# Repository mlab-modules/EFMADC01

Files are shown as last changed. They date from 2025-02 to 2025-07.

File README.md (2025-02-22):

# EFMADC01 - Electric Field Mill ADC Module

The **EFMADC01** module is designed to provide an **analog front-end** and **ADC conversion** for [Electric Field Mill sensor](https://github.com/UniversalScientificTechnologies/THUNDERMILL01) development and experiments. It processes analog signals from the field mill electrodes and converts them into digital data for further processing.

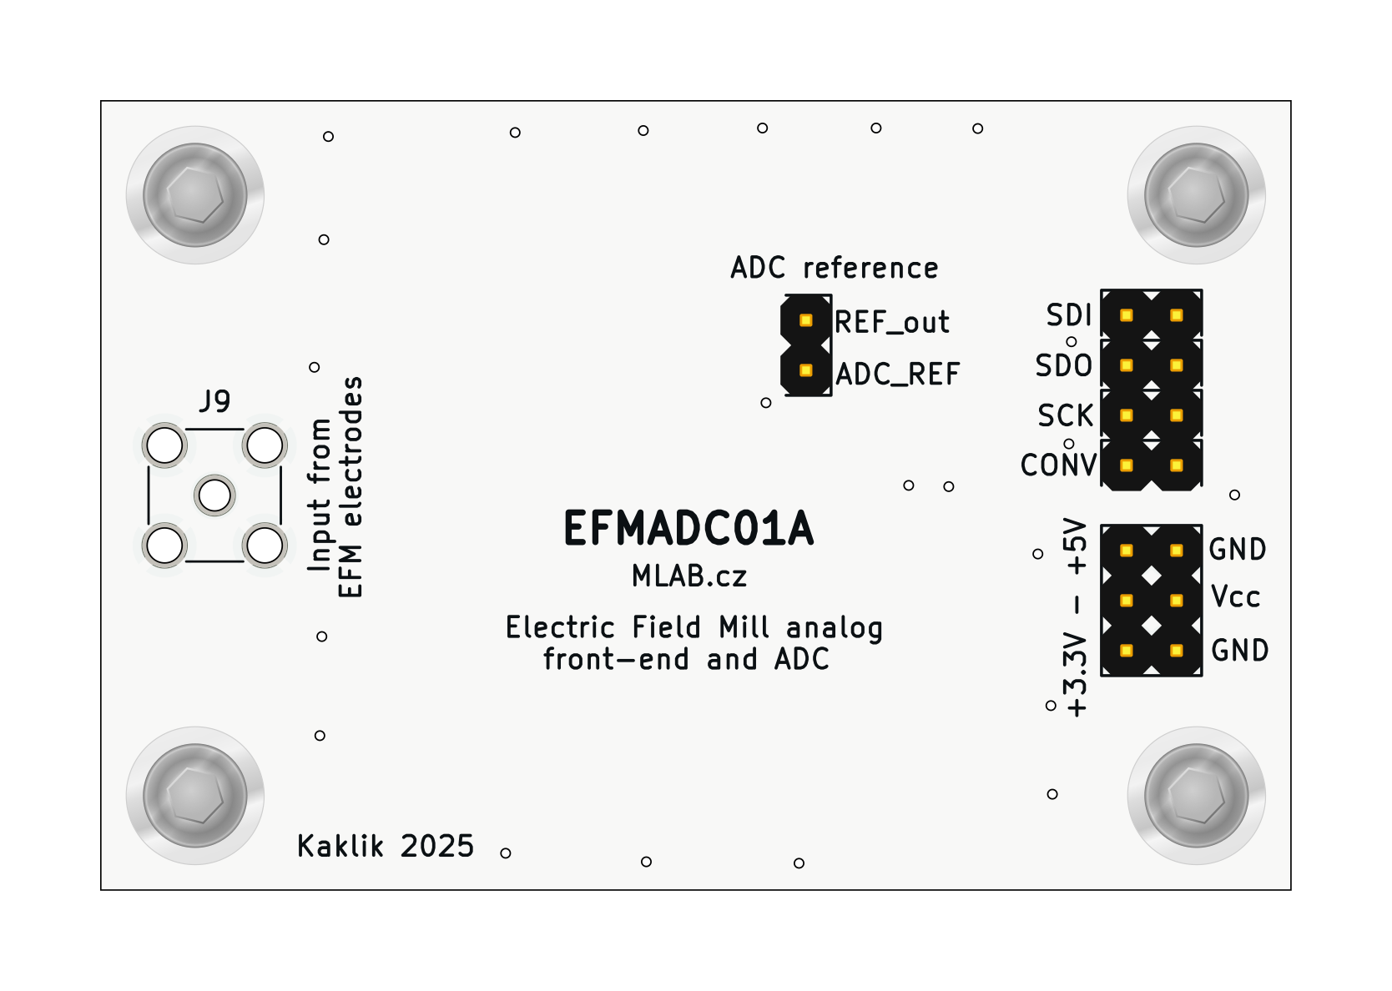
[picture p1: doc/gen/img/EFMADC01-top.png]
EFMADC01 top


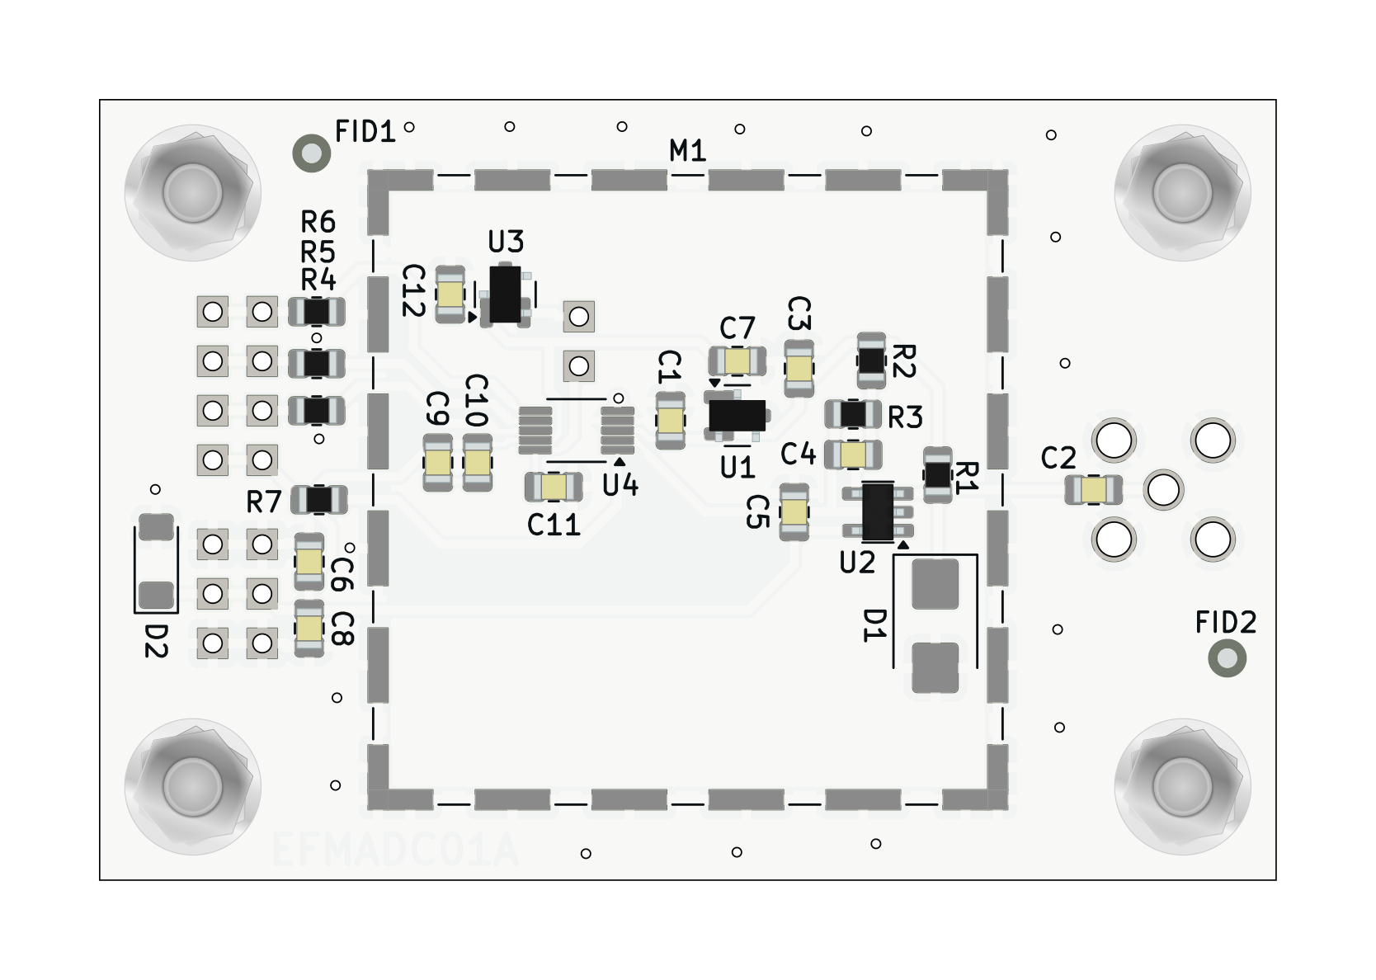
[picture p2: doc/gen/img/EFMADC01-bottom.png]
EFMADC01 bottom


## Features

- **High-Precision ADC**: Utilizes the **LTC1865** 16-bit, 250ksps analog-to-digital converter.
- **Low-Noise Analog Front End**: Incorporates **OPA314** operational amplifiers for signal conditioning.
- **Precision and stable Voltage Reference**: Includes a **1.25V reference** for accurate ADC operation.
- **Flexible Power Supply**: Supports **3.3V to 5V** operation.
- **RF Shielding**: Equipped with shielding to reduce external interference.
- **MCX Connector Input**: Enables high-quality signal connection.

## Functional Description

The **EFMADC01** module consists of three main blocks:

1. **Analog Front End (AFE)**:
   - Uses **OPA314** operational amplifiers for signal buffering and amplification.
   - High-impedance resistor (10MΩ) allows direct signal acquisition from the field mill sensor electrodes.

2. **ADC Conversion**:
   - **LTC1865-MS** ADC provides **16-bit resolution** with **250ksps sampling rate**.
   - Accepts differential input signals and supports SPI communication.

3. **Power and Reference**:
   - Powered by an external **3.3V or 5V** supply.
   - Features a **BZV55C-6.2V** Zener diode for overvoltage protection.
   - Uses a **1.25V precision voltage reference** for ADC stability.

## Hardware Connections

### Power Supply:
- **VCC**: Accepts **3.3V to 5V** input.
- **GNDA** and **GND**: Ground connections.

### Analog Input:
- **J9 (MCX Connector)**: Main analog signal input.
- **Operational amplifier stage** conditions the signal before ADC conversion.

## Typical Application

The **EFMADC01** module is primarily used in electric field mill experiments to measure atmospheric electric fields. It can also be employed in low-frequency scientific measurements where high-resolution ADC conversion is required.

## Schematic

For detailed circuit information, please take a look at the [EFMADC01 schematic](/doc/gen/EFMADC01-schematic.pdf) in the documentation.

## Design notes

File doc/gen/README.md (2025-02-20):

# PCB

Board size: 60.45x40.13 mm (2.38x1.58 inches)

- This is the size of the rectangle that contains the board
- Thickness: 1.6 mm (63 mils)
- Material: FR4
- Finish: Immersion gold
- Layers: 2
- Copper thickness: 35 µm

Solder mask: TOP / BOTTOM

- Color: White

Silk screen: TOP / BOTTOM

- Color: Black

Special features:

- Castellated pads
- Edge plating

Stackup:

| Name | Type | Color | Thickness [µm]| Material | Er | Loss tan |
|---|---|---|---|---|---|---|
| F.SilkS | Top Silk Screen | Black | | | | |
| F.Paste | Top Solder Paste | | | | | |
| F.Mask | Top Solder Mask | White | 10 | | | |
| F.Cu | copper | | 35 | | | |
| dielectric 1 | core | | 1510 | FR4 | 4.5 | 0.020 |
| B.Cu | copper | | 35 | | | |
| B.Mask | Bottom Solder Mask | White | 10 | | | |
| B.Paste | Bottom Solder Paste  | | | | | |
| B.SilkS | Bottom Silk Screen | Black | | | | |

# Important sizes

Clearance: 0.2 mm (8 mils)

Track width: 0.2 mm (8 mils)

- By design rules: 0.2 mm (8 mils)

Drill: 0.5 mm (20 mils)

- Vias: 0.5 mm (20 mils) [Design: 0.4 mm (16 mils)]
- Pads: 1.0 mm (39 mils)
- The above values are real drill sizes, they add 0.1 mm (4 mils) to plated holes (PTH)

Via: 0.8/0.4 mm (31/16 mils)

- By design rules: 0.4/0.3 mm (16/12 mils)
- Micro via: yes [0.2/0.1 mm (8/4 mils)]
- Buried/blind via: yes
- Total: 22 (thru: 22 buried/blind: 0 micro: 0)

Outer Annular Ring: 0.15 mm (6 mils)

- By design rules: 0.23 mm (9 mils)

Eurocircuits class: 4B
- Using min drill 0.5 mm for an OAR of 0.15 mm

# General stats

Components count: (SMD/THT)

- Top: 0/11 (THT)
- Bottom: 28/0 (SMD)

Defined tracks:

- 0.2 mm (8 mils)
- 0.25 mm (10 mils)
- 0.3 mm (12 mils)
- 0.45 mm (18 mils)
- 0.5 mm (20 mils)

Used tracks:

- 0.2 mm (8 mils) (8) defined: yes
- 0.25 mm (10 mils) (23) defined: yes
- 0.3 mm (12 mils) (1) defined: yes
- 0.45 mm (18 mils) (120) defined: yes

Defined vias:

Used vias:

- 0.8/0.4 mm (31/16 mils) (Count: 22, Aspect: 2.0 A) defined: no

Holes (excluding vias):

- 0.89 mm (35 mils) (16)
- 1.5 mm (59 mils) (1)
- 1.7 mm (67 mils) (4)
- 3.0 mm (118 mils) (4)

Oval holes:

Drill tools (including vias and computing adjusts and rounding):

- 0.5 mm (20 mils) (22)
- 1.0 mm (39 mils) (16)
- 1.6 mm (63 mils) (1)
- 1.8 mm (71 mils) (4)
- 3.1 mm (122 mils) (4)

Solder paste stats:

Using a paste with 87.75 % alloy, that has an specific gravity for the alloy of 7.4 g/cm³
and 1.0 g/cm³ for the flux. This paste has an specific gravity of  4.15 g/cm³.

The stencil thickness is  0.12 mm.

| Side | Pads with paste | Area [mm²] | Paste [g] |
|---|---|---|---|
| Total  | 91 | 166.21 | 0.83 |

Note: this is just an approximation to the theoretical value. Margins of the solder mask and waste aren't computed.

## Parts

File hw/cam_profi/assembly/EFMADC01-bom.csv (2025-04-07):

Component | Description | Part | References | Value | Footprint | Quantity Per PCB | Datasheet | ust_id
1 | Unpolarized capacitor | C | C4 | 1nF | C_0805_2012Metric | 1 | ~ | 5c70984812875079b91f8ba6
2 | Unpolarized capacitor | C | C1C2C3C5C6C7C10C11C12 | 100nF | C_0805_2012Metric | 9 | ~ | 6508260b462c6d9e720541f1 5c70984712875079b91f8b4c
3 | Unpolarized capacitor | C | C8C9 | 10uF | C_0805_2012Metric | 2 | ~ | 5c70984812875079b91f8bbe
4 | Zener diode | D_Zener | D2 | BZV55C-6,2V | D_MiniMELF | 1 | ~ | 604b0326128750769e5b0f93
5 | 600W unidirectional Transil Transient Voltage Suppressor, 12Vrwm, DO-214AA | SM6T12A | D1 | UCLAMP3301H.TCT | D_SMB | 1 | https://www.st.com/resource/en/datasheet/sm6t.pdf | 612514fe1287500165a976f3
6 | 2x03 2.54 mm pitch header, 2 pins next to each other are connected | HEADER_2x03_PARALLEL | J1 | 3.3-5V | Straight_2x03 | 1
7 | 2x01 2.54 mm pitch header | HEADER_2x01 | J2 | HEADER_2x01 | Straight_2x01 | 1
8 | 2x01 2.54 mm pitch header, 2 pins next to each other are connected | HEADER_2x01_PARALLEL | J4J5J6J7 | HEADER_2x01_PARALLEL | Straight_2x01 | 4
9 | coaxial connector (BNC, SMA, SMB, SMC, Cinch/RCA, LEMO, ...) | Conn_Coaxial | J9 | MCX | SMA_Amphenol_901-144_Vertical | 1 | ~ | 5fa10cc512875025b39779f6
10 | Two-piece EMI RF shielding cabinet | RFShield_TwoPieces | M1 | RFShield_TwoPieces | Laird_Technologies_BMI-S-204-F_32.00x32.00mm | 1 | ~ | 5c72751c1287500b4e11301a
11 | Resistor | R | R4R5R6R7 | 33R | R_0805_2012Metric | 4 | ~ | 5c70984512875079b91f8970
12 | Resistor | R | R2 | 2k2 | R_0805_2012Metric | 1 | ~ | 5c70984512875079b91f895e
13 | Resistor | R | R3 | 10k | R_0805_2012Metric | 1 | ~ | 5c70984512875079b91f8962
14 | Resistor | R | R1 | 10M | R_0805_2012Metric | 1 | ~ | 5c70984712875079b91f8b6d
15 | 1.5V 25μA Micropower Voltage Reference, SOT-23 | ISL21070CIH320Z-TK | U1 | ISL21080CIH315ZT | SOT-23 | 1 | http://www.intersil.com/content/dam/Intersil/documents/fn75/fn7599.pdf | 5c70984712875079b91f8b0a
16 | 2.0V 25μA Micropower Voltage Reference, SOT-23 | ISL21070CIH320Z-TK | U3 | ISL21080CIH330Z-TK | SOT-23 | 1 | http://www.intersil.com/content/dam/Intersil/documents/fn75/fn7599.pdf | 67d36d64ee7fc534862c3ebc
17 | Dual channel 16-bit SAR Analog to Digital Converter, 5V supply, 150ksps, SPI interface | LTC1865-MS | U4 | LTC1865-MS | MSOP-10_3x3mm_P0.5mm | 1 | https://www.analog.com/media/en/technical-documentation/data-sheets/18645fb.pdf | 651eae84462c6d9e7205573b
18 | 50μV V OS, 0.25μV/°C, 35μA CMOS OPERATIONAL AMPLIFIERS, Zerø-Drift Series, SOT | OPA330xxDBV | U2 | OPA314 | SOT-23-5 | 1 | http://www.ti.com/lit/ds/symlink/opa330.pdf | 5c70984412875079b91f879a

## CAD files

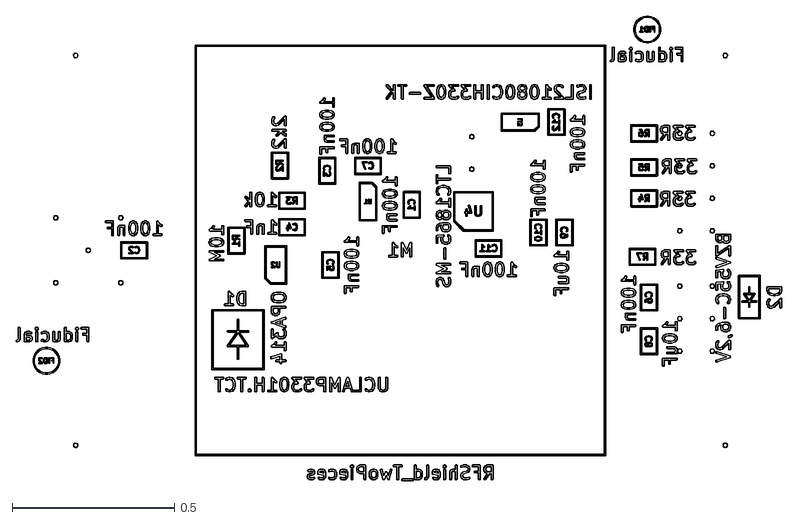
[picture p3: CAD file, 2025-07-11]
doc/gen/dxf/EFMADC01-B_Fab.dxf
2.36 x 1.43

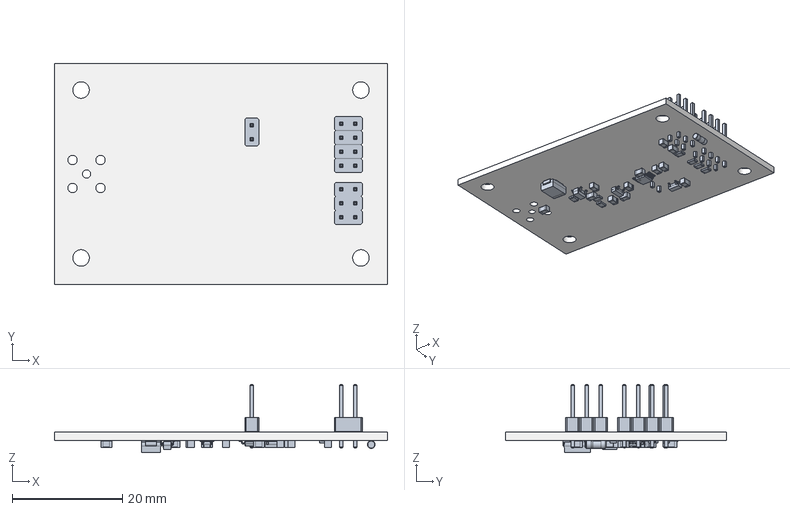
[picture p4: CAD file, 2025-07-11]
doc/gen/EFMADC01.step
60.5 x 40.1 x 12.4 mm
PinHeader_2x01_P2.54mm_Vertical x 5
PinHeader_2x03_P2.54mm_Vertical
R_0805_2012Metric x 7
SOT-23 x 2
C_0805_2012Metric x 12
D_MiniMELF
MSOP-10_3x3mm_P0.5mm
D_SMB
SOT-23-5
kibot_ljoc_gb1_PCB

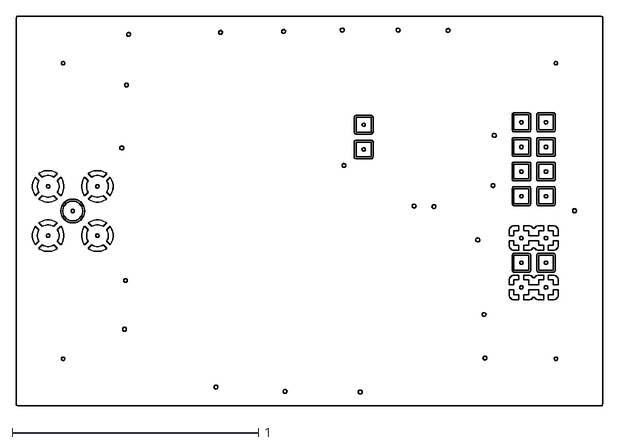
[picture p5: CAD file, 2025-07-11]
doc/gen/dxf/EFMADC01-F_Cu.dxf
2.38 x 1.58

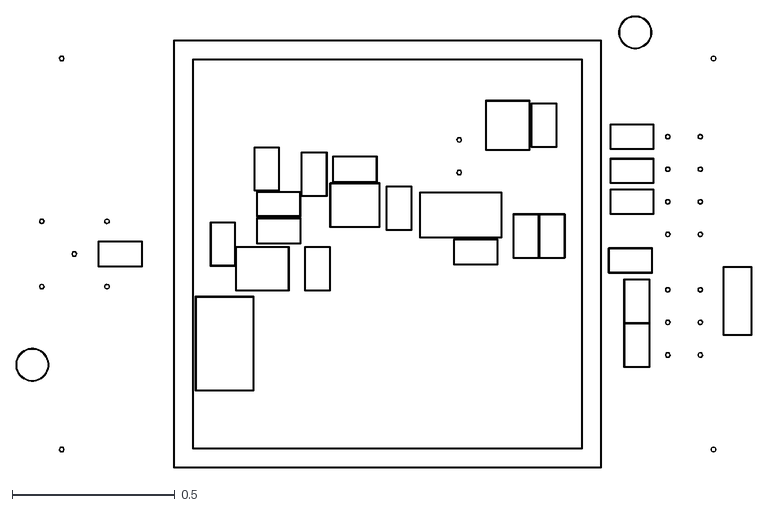
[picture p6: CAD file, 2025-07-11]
doc/gen/dxf/EFMADC01-B_Courtyard.dxf
2.26 x 1.39

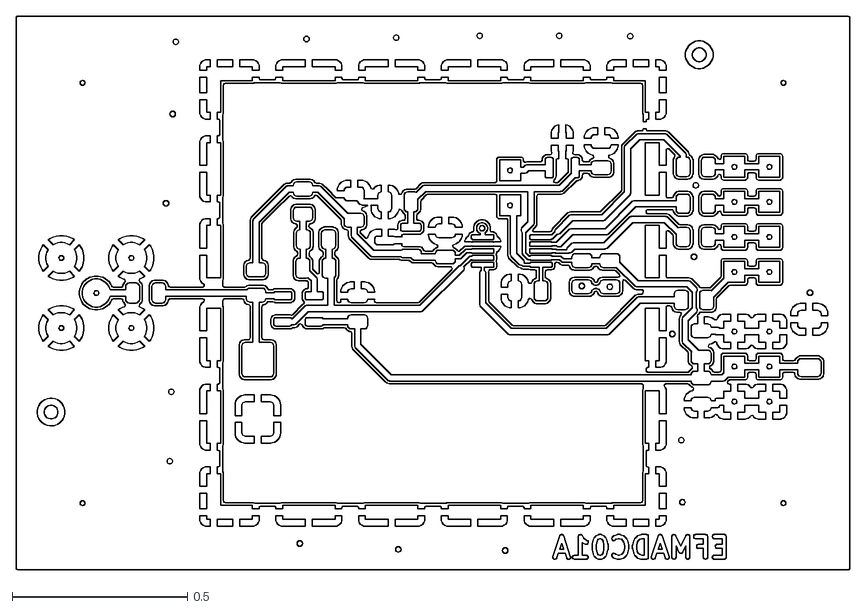
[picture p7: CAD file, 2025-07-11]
doc/gen/dxf/EFMADC01-B_Cu.dxf
2.38 x 1.58

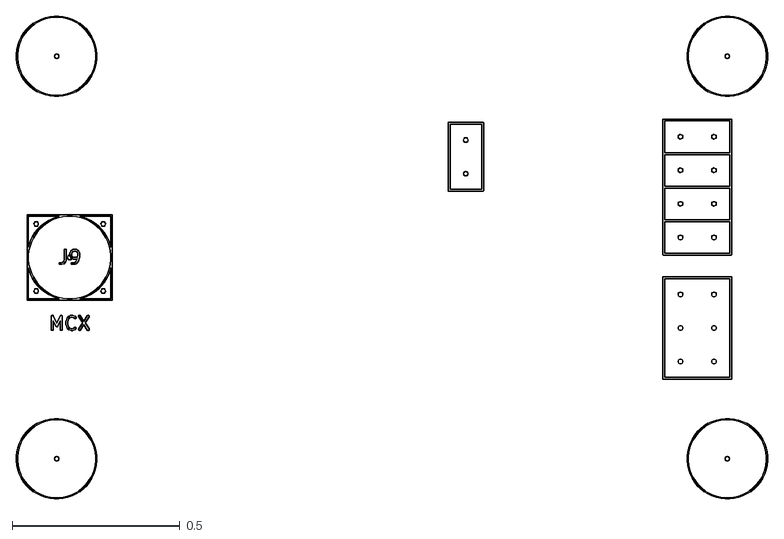
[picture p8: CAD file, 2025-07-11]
doc/gen/dxf/EFMADC01-F_Fab.dxf
2.24 x 1.44

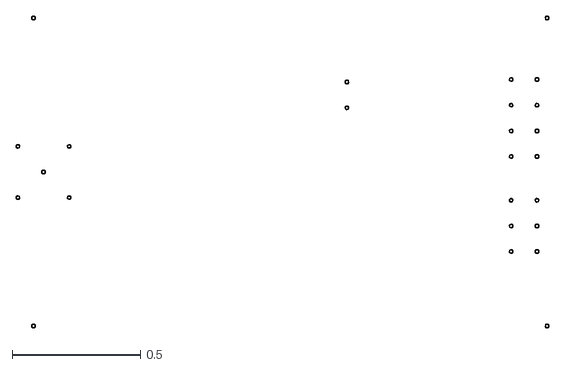
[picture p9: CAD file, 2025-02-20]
doc/gen/dxf/EFMADC01-User_Drawings.dxf
2.07 x 1.21

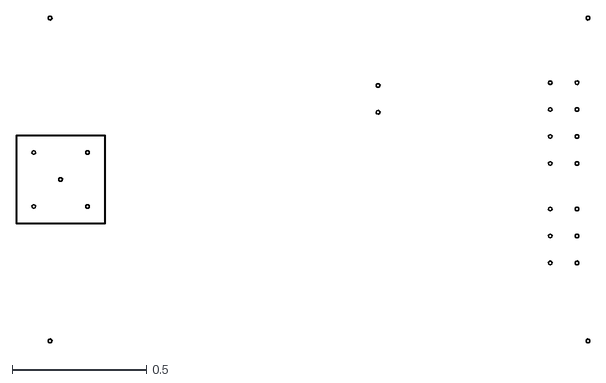
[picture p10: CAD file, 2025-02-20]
doc/gen/dxf/EFMADC01-F_Courtyard.dxf
2.13 x 1.21

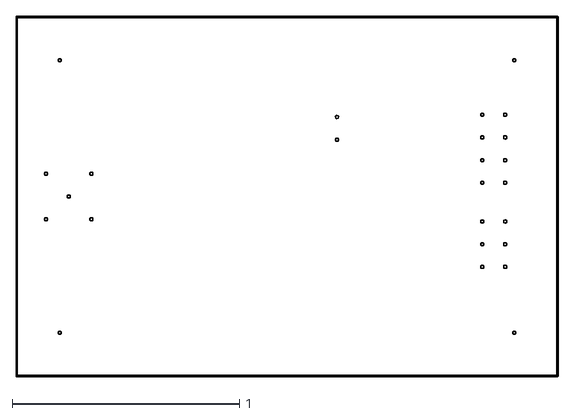
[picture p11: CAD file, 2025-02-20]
doc/gen/dxf/EFMADC01-Edge_Cuts.dxf
2.39 x 1.59

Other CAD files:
doc/gen/dxf/EFMADC01-B_Adhesive.dxf
doc/gen/dxf/EFMADC01-F_Adhesive.dxf
doc/gen/dxf/EFMADC01-B_Mask.dxf
doc/gen/dxf/EFMADC01-B_Paste.dxf
doc/gen/dxf/EFMADC01-B_Silkscreen.dxf
doc/gen/dxf/EFMADC01-F_Mask.dxf
doc/gen/dxf/EFMADC01-F_Paste.dxf
doc/gen/dxf/EFMADC01-F_Silkscreen.dxf

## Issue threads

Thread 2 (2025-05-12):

GND/GNDA connection to probes

roman-dvorak, 2025-05-12:
Nebylo by lepší, kdyby do MCX konektoru bylo přivedeno GNDA?
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

kaklik, 2025-05-12:
GND je tam schválně. Protože je to vnější zem, na které může být kde co.  Ta je potom v jednom bodě spojená s GNDA, proti které je následně aplikováno zesílení.

Myslím, že v případě jednoduchého RF konektoru s jedním stíněním, to ani lépe udělat nejde.  Lepší řešení je jen případ, kdy by okolo koaxu mohla být z venku GND, pak by dávalo smysl na konektor vyvést GNDA. V opačném případě to jen způsobí průnik rušení do GNDA po stínění konektoru.

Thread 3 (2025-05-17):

Rozšíření modulu o synchronizační bit pro identifikaci počátku otáčky

kaklik, 2025-05-17:
Modul EFMADC01 využívá ADC typu LTC1864/LTC1865 pro sekvenční měření hodnot řízené signálem `CONV` z mikrořadiče. Pro určení polarity pole je ale potřeba mít převody fázově synchronizované se začátkem otáčky.

V současné verzi je synchronizace řešena externě, což vyžaduje další signály do MCU. To by mělo jít eleminovat jednoduchou logikou přímo v modulu, která umožní zakódování informace o fázi otáčky do 17. bitu SPI přenosu bez nutnosti měnit chování ADC.

Fakticky by šlo využít faktu, že optická závora je open-drain a připojit ji rovnou na výstup ADC na signál SDO. Takové řešení je extrémně jednoduché, ale zároveň nepoužívá SPI fyzickou vrstvu úplně korektně, protože pak by se jednak mohl stav SDO měnit asynchronně s hodinami. Zároveň se tím ale zachovává možnost pro MCU číst optickou závoru a tím i fázi velmi přesně.

---

#### Návrh řešení:

Použitím kotoučku s delší fázovou značkou následujících součástek:

* Čítač (např. MC74HC161A) řízený hodinami `SCK`, resetovaný signálem `CONV`, který generuje signál `RCO` při dosažení 16. taktu.
* D-Flip-Flop (např. 74HC74), který při 16. taktu (RCO = HIGH) vzorkuje stav vstupu z optické závory (např. synchronizační značky na rotoru).
* V následujícím (17.) taktu se tento stav poskytne na výstupu MISO namísto dat z ADC.
* Výstup ADC (`SDO`) je propojen přímo na MISO pro prvních 16 taktů; 17. takt čte hodnotu `Q` z D-FF.

#### Výsledné chování

* Standardní SPI přenos: **16 bitů dat z ADC + 1 bit synchronizační informace**.
* MCU čte data jako běžný SPI master, ale poslední bit může použít k identifikaci počátku otáčky.
* Není nutné přidávat další signál z optické závory do MCU.
* Možné zachovat kompatibilitu s původním chováním i bez použití synchronizační značky.

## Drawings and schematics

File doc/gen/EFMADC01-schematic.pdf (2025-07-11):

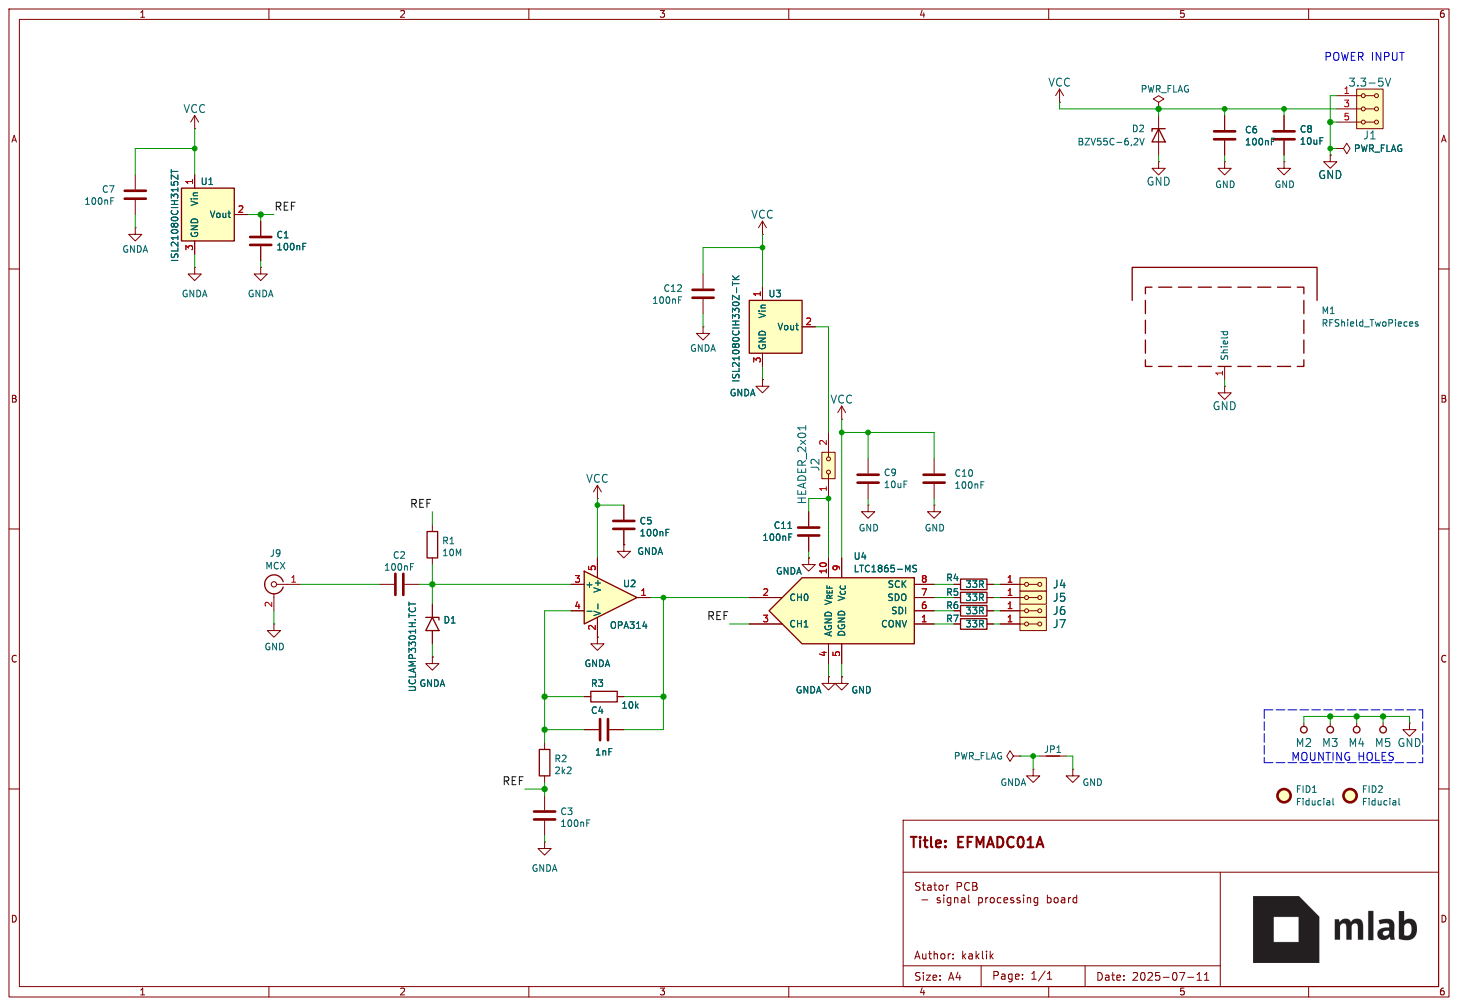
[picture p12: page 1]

GND GNDA GNDA Vin
GNDA C5

3 Vout 2 U3 ISL21080CIH330Z-TK CH0 2 CH1 3 V_{REF}10 AGND

5 SCK 8 SDO 7 SDI 6 CONV 1 C11

5 SCK 8 SDO 7 SDI 6 CONV 1 U4
LTC1865-MS

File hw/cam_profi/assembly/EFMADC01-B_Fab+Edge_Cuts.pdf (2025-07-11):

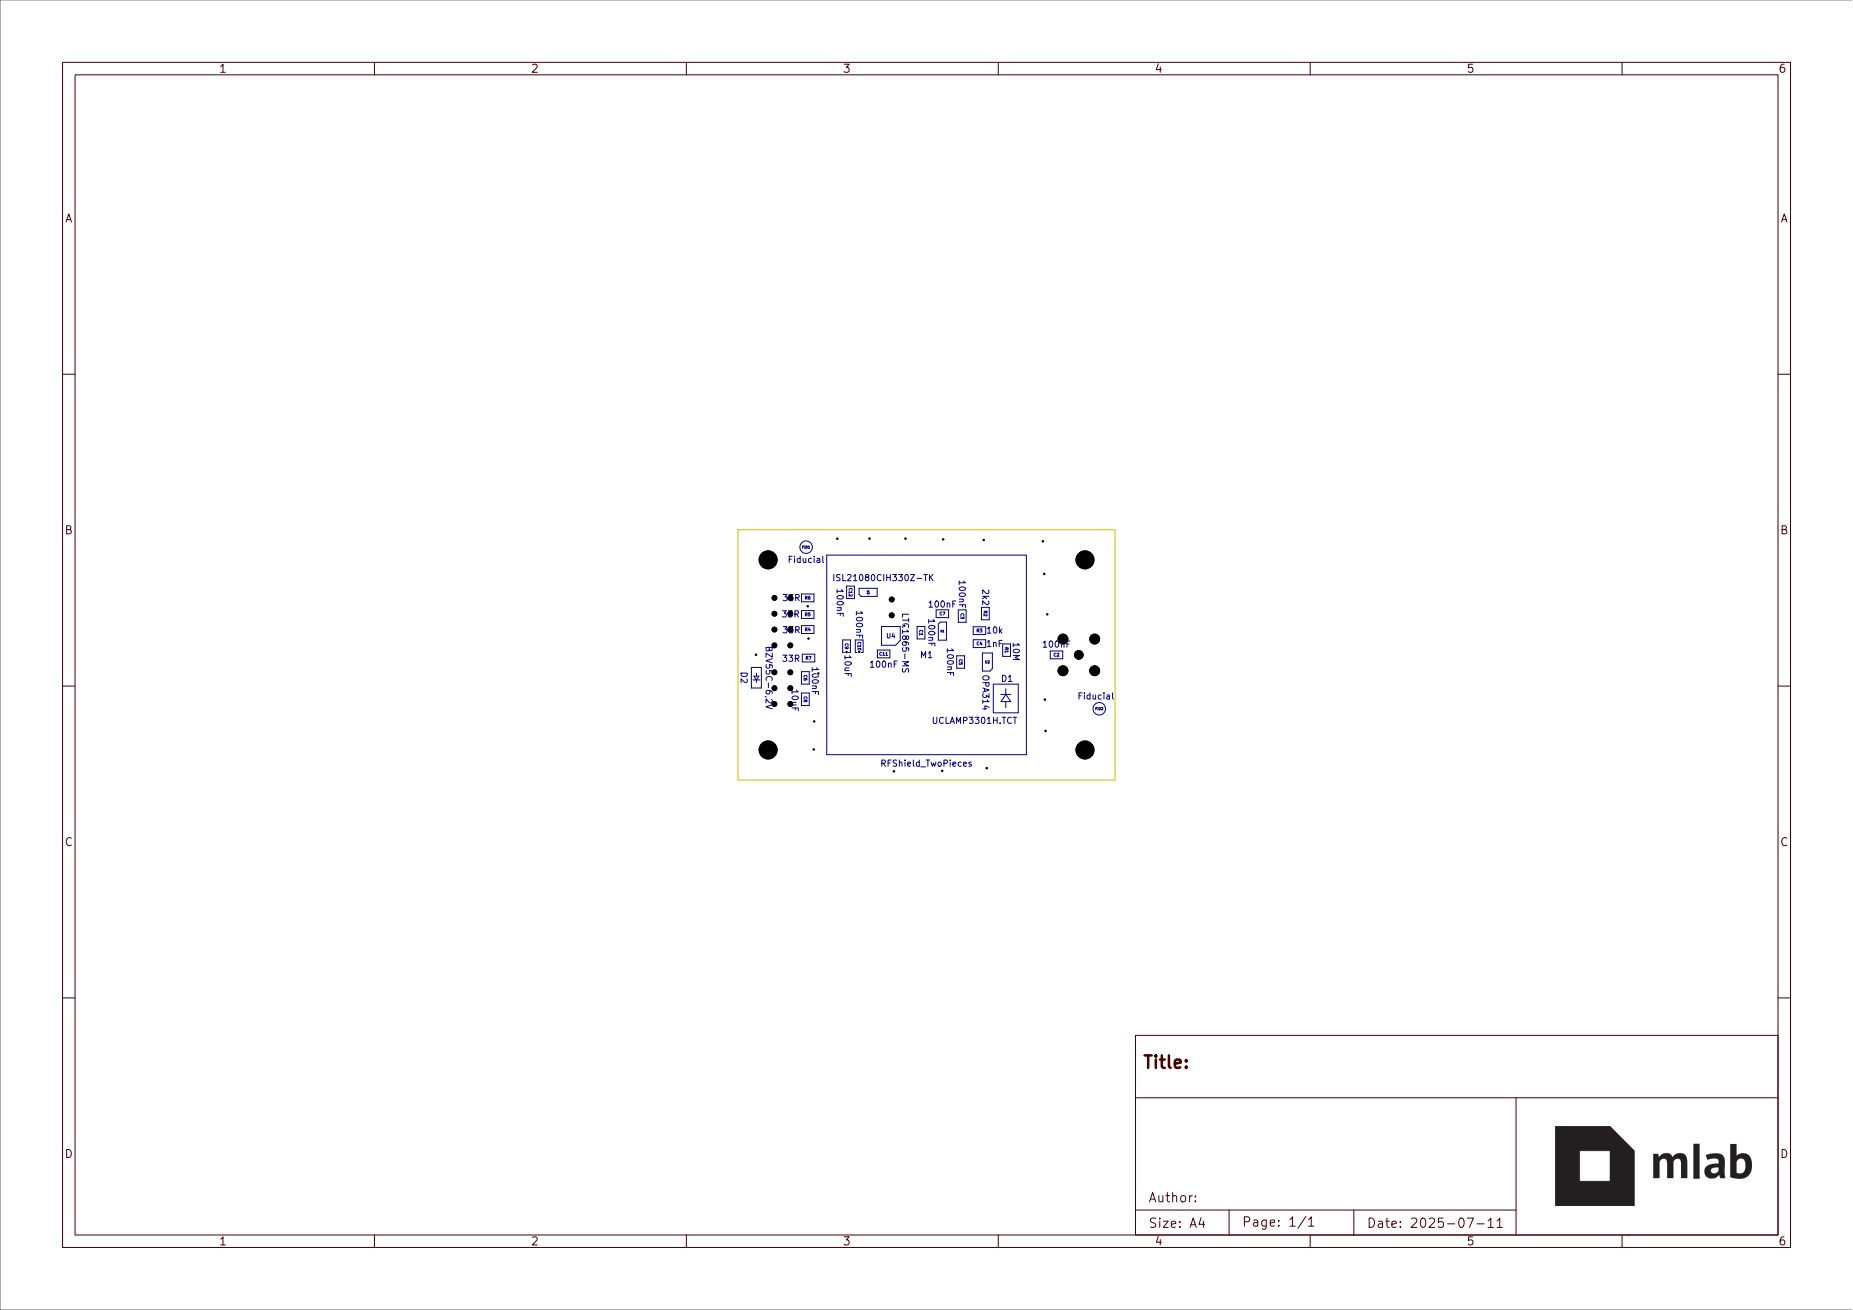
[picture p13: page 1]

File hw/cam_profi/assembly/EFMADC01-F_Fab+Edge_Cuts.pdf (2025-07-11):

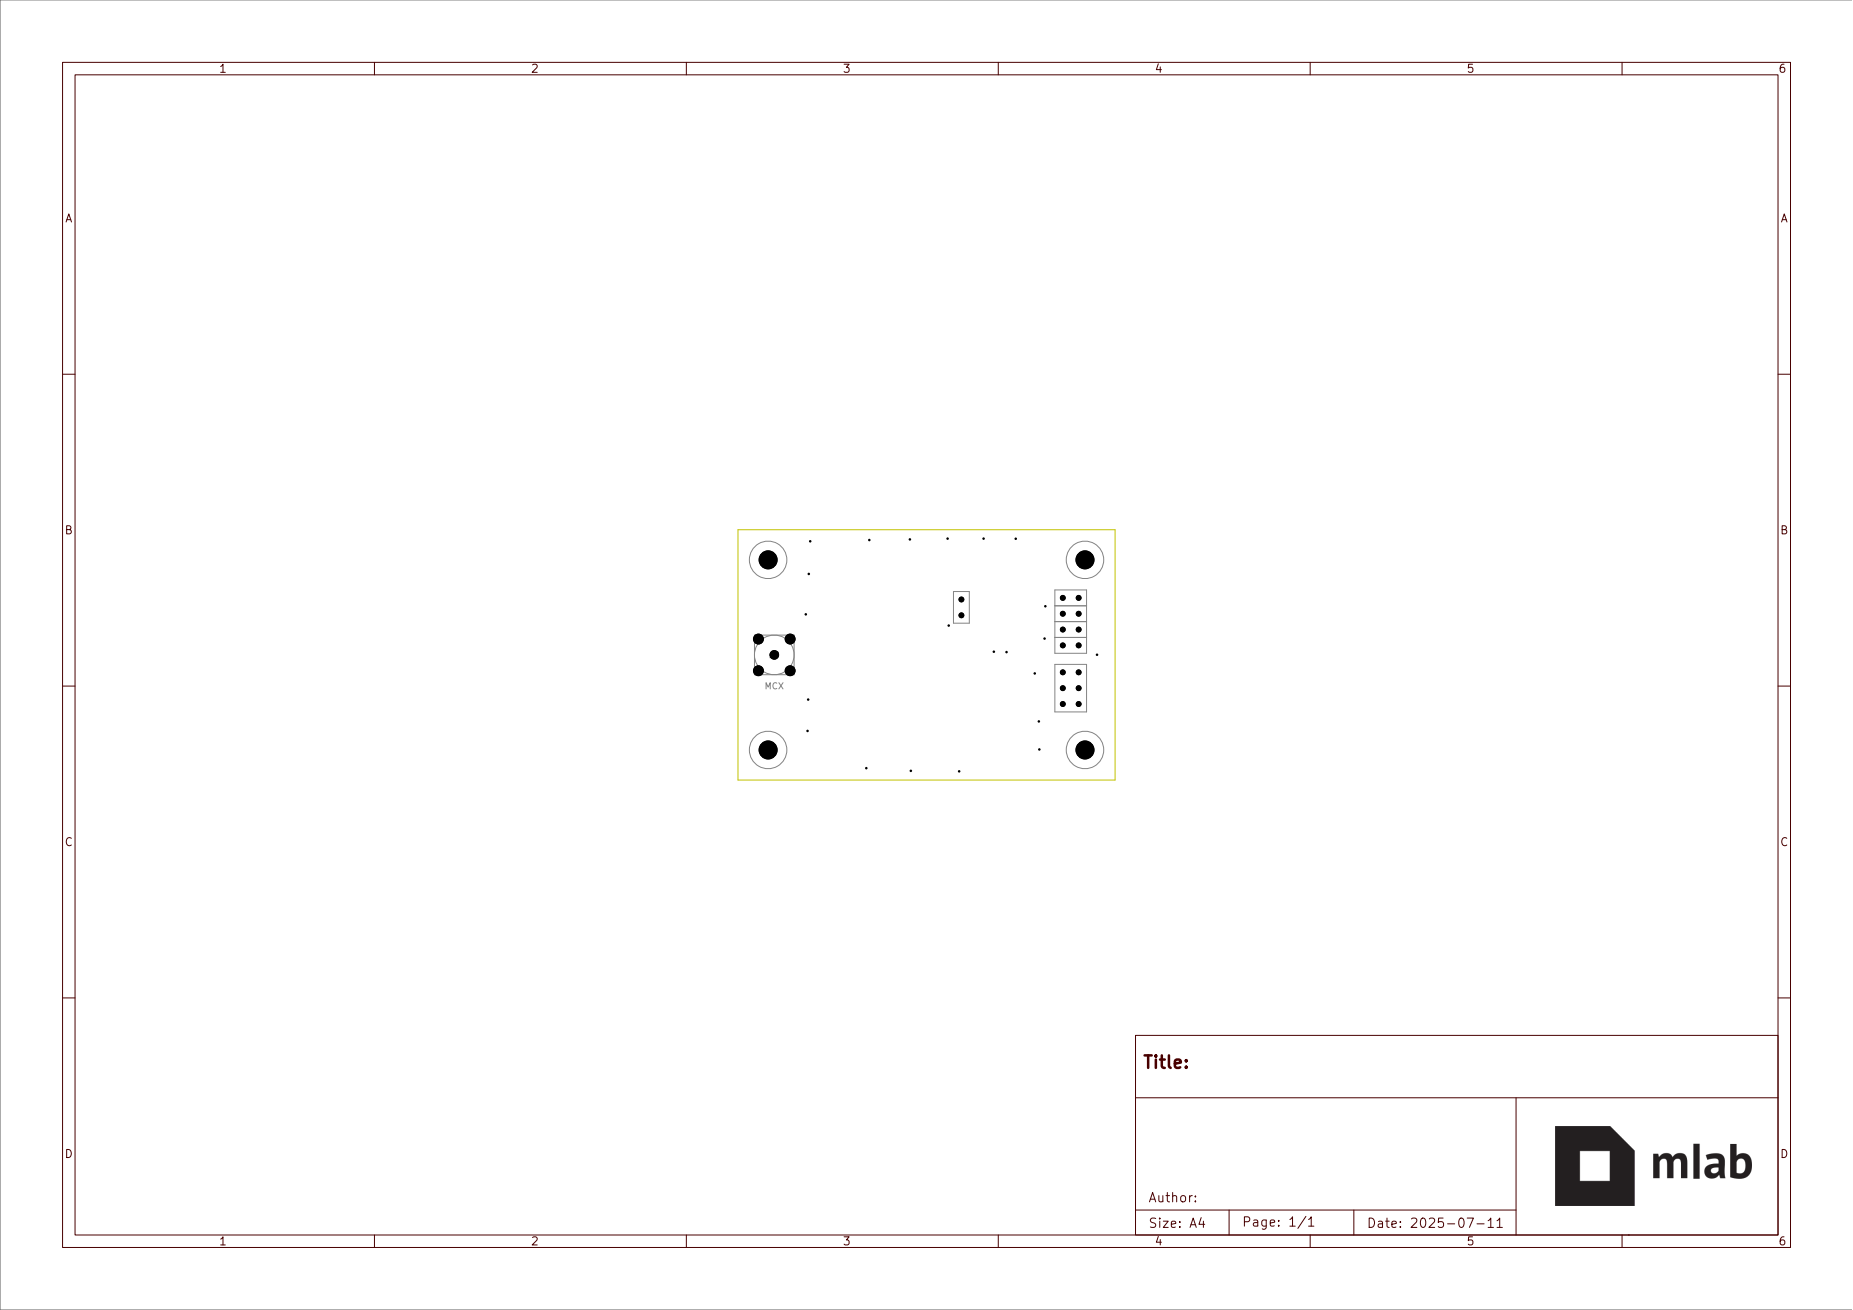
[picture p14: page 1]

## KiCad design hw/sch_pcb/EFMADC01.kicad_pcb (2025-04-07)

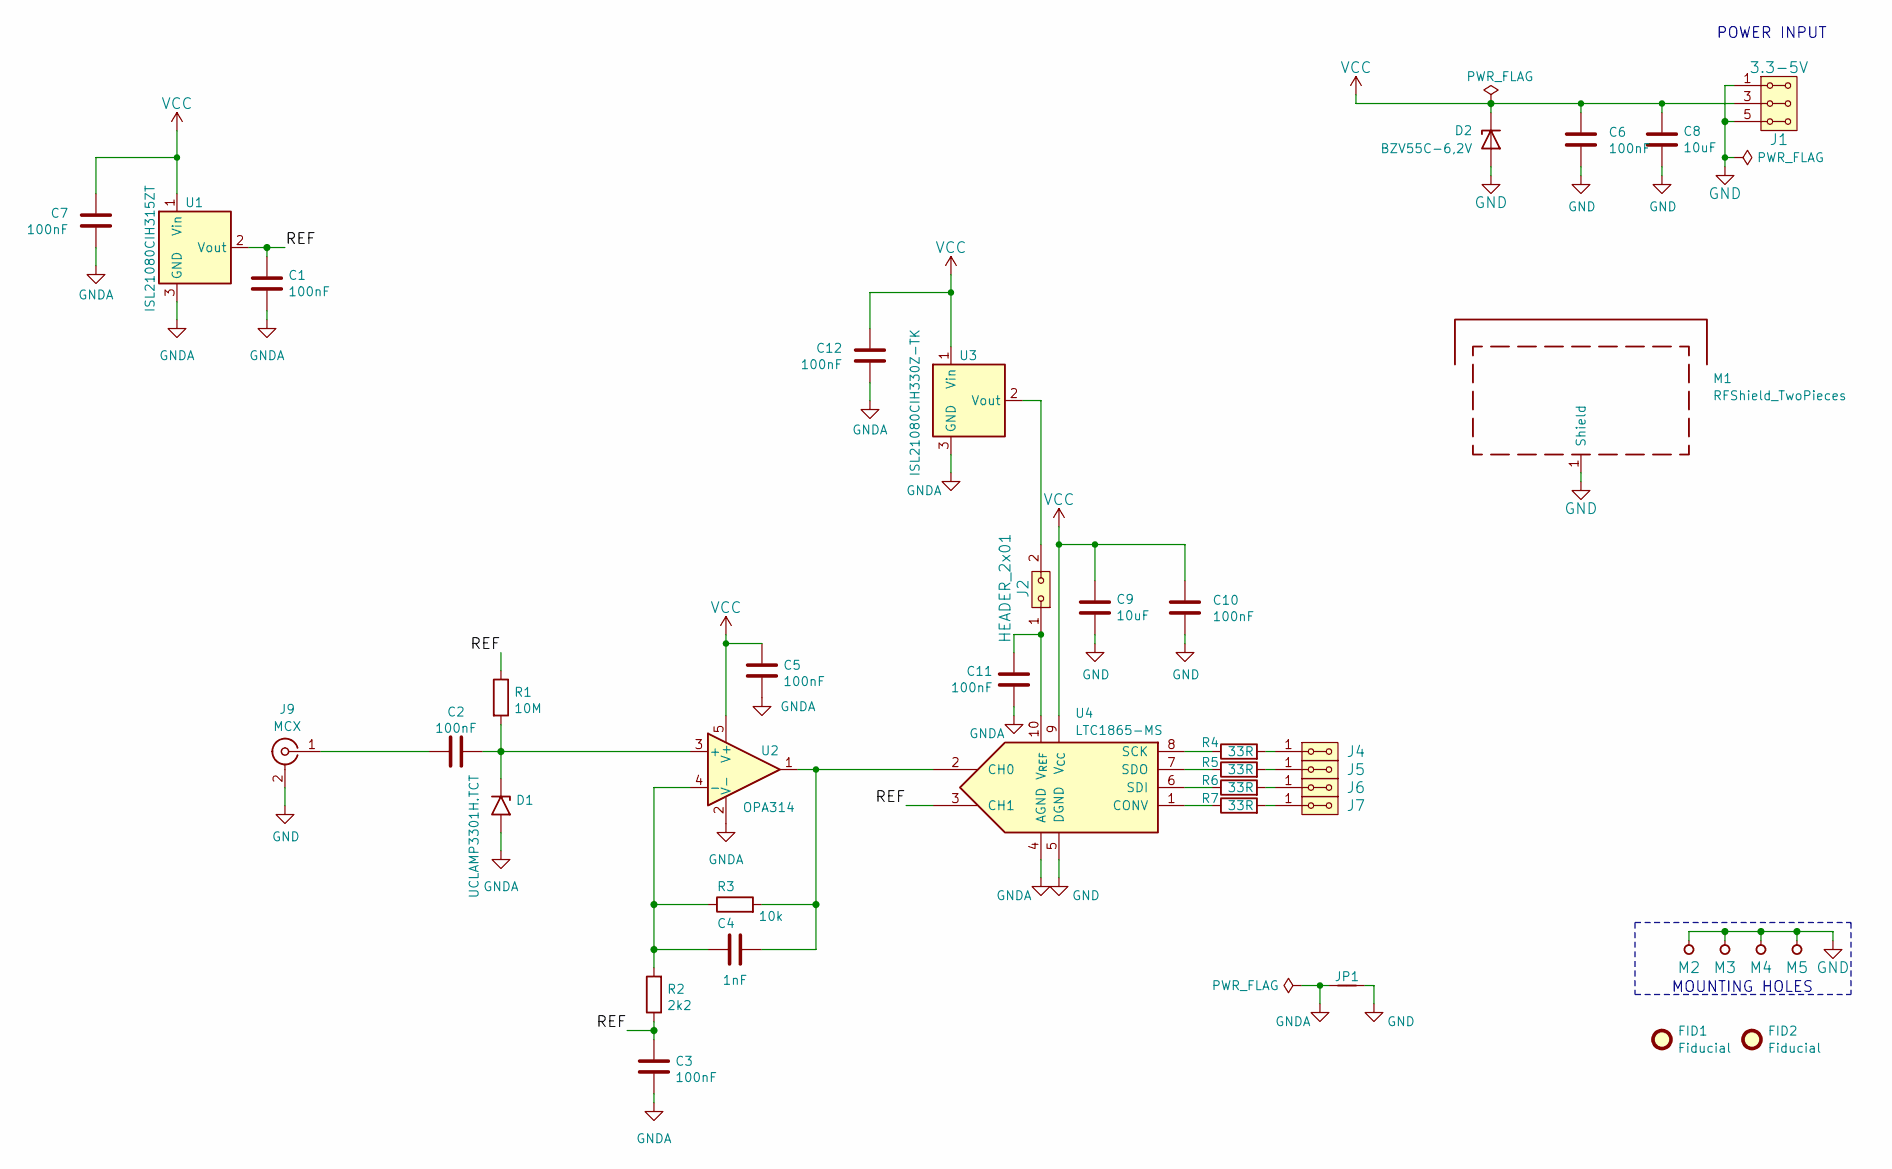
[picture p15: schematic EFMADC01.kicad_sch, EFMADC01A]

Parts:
C1, C2, C3, C5, C6, C7, C10, C11, C12: 100nF; C_0805_2012Metric
C4: 1nF; C_0805_2012Metric
C8, C9: 10uF; C_0805_2012Metric
D1: UCLAMP3301H.TCT; D_SMB
D2: BZV55C-6,2V; D_MiniMELF
FID1, FID2: Fiducial; Fiducial_1mm_Mask2mm
J1: 3.3-5V; Straight_2x03
J2: HEADER_2x01; Straight_2x01
J4, J5, J6, J7: HEADER_2x01_PARALLEL; Straight_2x01
J9: MCX; SMA_Amphenol_901-144_Vertical
JP1: Jumper_2_Bridged; NetTie-2_SMD_Pad0.5mm
M1: RFShield_TwoPieces; Laird_Technologies_BMI-S-204-F_32.00x32.00mm
M2, M3, M4, M5: HOLE; MountingHole_3mm
R1: 10M; R_0805_2012Metric
R2: 2k2; R_0805_2012Metric
R3: 10k; R_0805_2012Metric
R4, R5, R6, R7: 33R; R_0805_2012Metric
U1: ISL21080CIH315ZT; SOT-23
U2: OPA314; SOT-23-5
U3: ISL21080CIH330Z-TK; SOT-23
U4: LTC1865-MS; MSOP-10_3x3mm_P0.5mm

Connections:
/REF: C1.1, C3.2, R1.1, R2.1, U1.2 (Vout), U4.3 (CH1)
GND: C6.2, C8.2, C9.2, C10.2, D2.2 (A), J1.1, J1.2, J1.5, J1.6, J9.2 (Ext), JP1.2, M1.1 (Shield), M2.1, M3.1, M4.1, M5.1, U4.5 (DGND)
GNDA: C1.2, C3.1, C5.1, C7.2, C11.2, C12.2, D1.2 (A2), JP1.1, U1.3 (GND), U2.2 (V-), U3.3 (GND), U4.4 (AGND)
unnamed: C2.2, D1.1 (A1), R1.2, U2.3 (+)
unnamed: J4.1, J4.2, R4.2
unnamed: J5.1, J5.2, R5.2
unnamed: J6.1, J6.2, R6.2
unnamed: J7.1, J7.2, R7.2
unnamed: C2.1, J9.1 (In)
unnamed: C4.1, R2.2, R3.1, U2.4 (-)
unnamed: J2.2, U3.2 (Vout)
unnamed: C4.2, R3.2, U2.1, U4.2 (CH0)
unnamed: R7.1, U4.1 (CONV)
unnamed: R4.1, U4.8 (SCK)
unnamed: R6.1, U4.6 (SDI)
unnamed: R5.1, U4.7 (SDO)
unnamed: C11.1, J2.1, U4.10 (V_{REF})
VCC: C5.2, C6.1, C7.1, C8.1, C9.1, C10.1, C12.1, D2.1 (K), J1.3, J1.4, U1.1 (Vin), U2.5 (V+), U3.1 (Vin), U4.9 (V_{CC})

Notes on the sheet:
MOUNTING HOLES
POWER INPUT

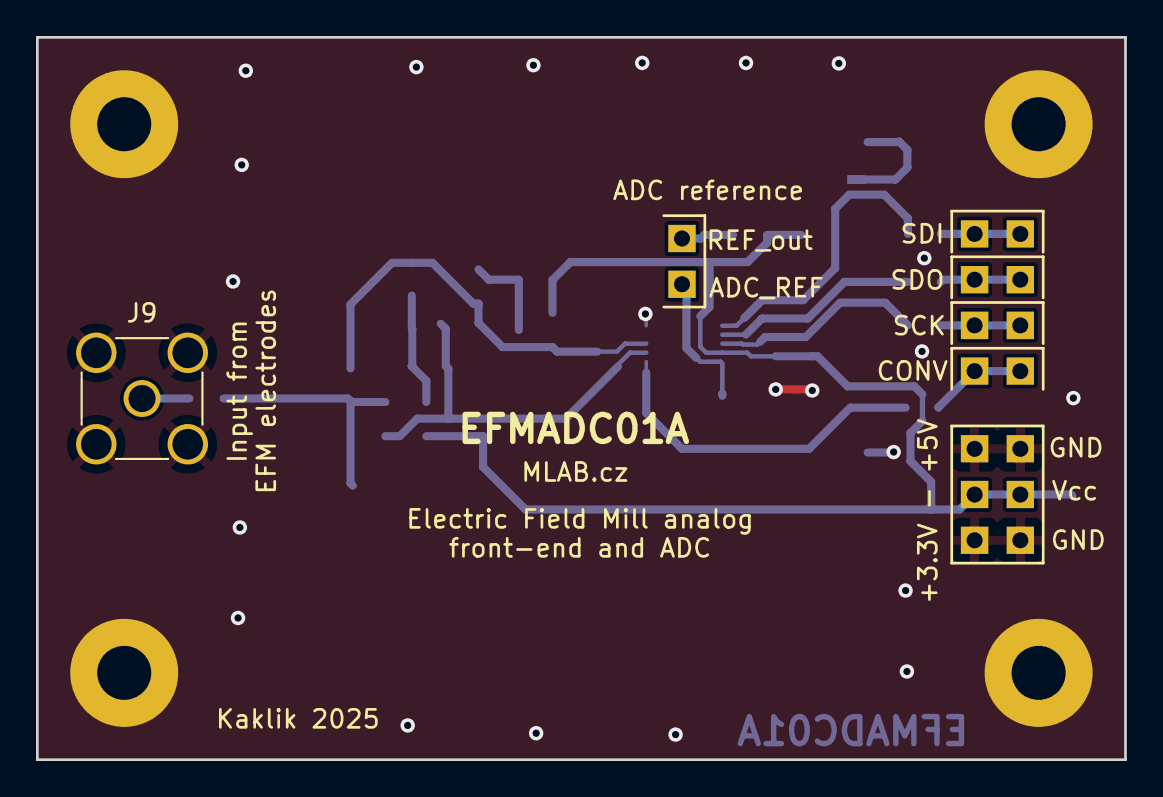
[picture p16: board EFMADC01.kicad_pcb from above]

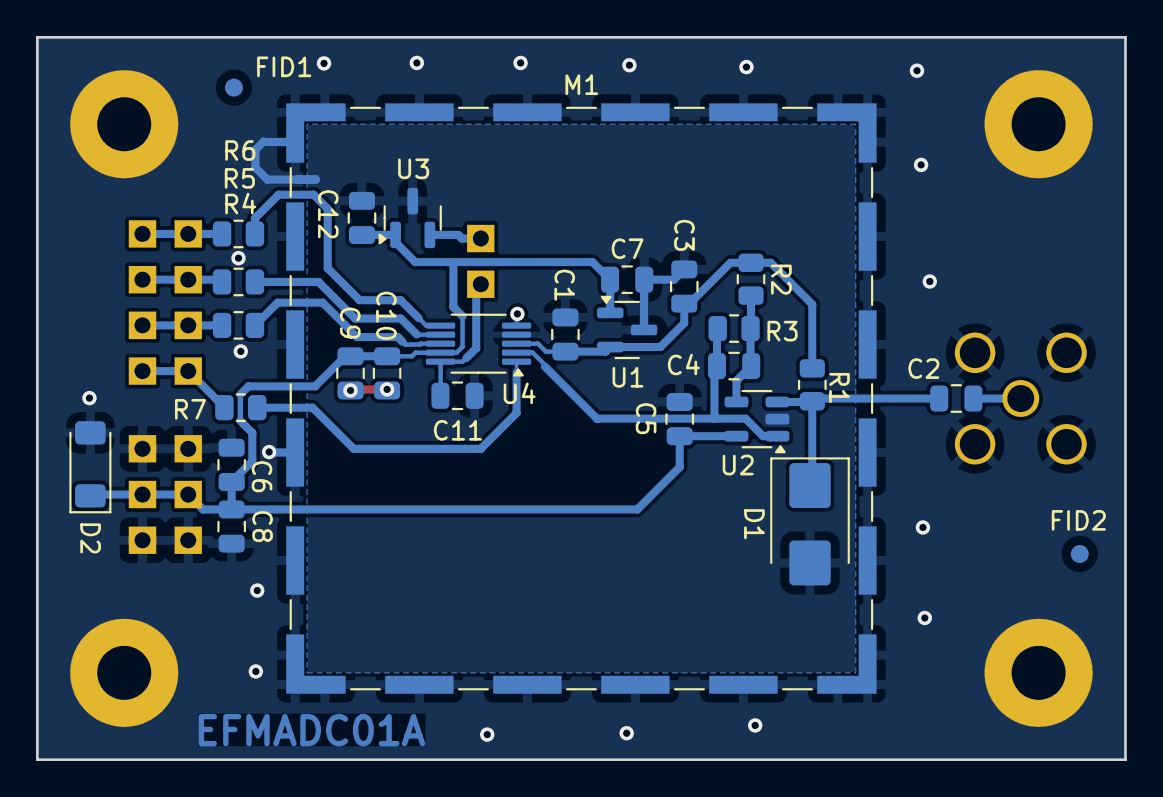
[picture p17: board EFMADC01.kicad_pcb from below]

Board: 2 copper layers, 60.5 x 40.1 mm, 40 parts (29 on the bottom side), 18 nets.

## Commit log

2025-02-16 Initial schematics of Electric Field milll ADC.
    [EFMADC01.kicad_pcb, EFMADC01.kicad_sch]
2025-02-16 Update actions products
    [EFMADC01-B_Adhesive.dxf, EFMADC01-B_Courtyard.dxf, EFMADC01-B_Cu.dxf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]
2025-02-17 Starting layout work.
    [EFMADC01.kicad_pcb]
2025-02-19 Rounted PCB Added silkscreen text.
    [EFMADC01.kicad_pcb, EFMADC01.kicad_sch]
2025-02-20 Improve silkscreen texts.
    [EFMADC01.kicad_pcb]
2025-02-20 Improve layout, adding vias.
    [EFMADC01.kicad_pcb]
2025-02-22 Update Fab layers.
    [EFMADC01.kicad_pcb]
2025-04-07 Cleanup net names in schematics.
    [EFMADC01.kicad_pcb, EFMADC01.kicad_sch]
